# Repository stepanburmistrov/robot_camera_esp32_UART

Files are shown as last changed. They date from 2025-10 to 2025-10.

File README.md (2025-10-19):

# Robot View (ESP32-CAM + Arduino) — веб-джойстик, стрим и управление колёсами

> **Проверено:** сборка и прошивка в Arduino IDE c **ESP32 Arduino core 3.0.7** и стандартным Arduino AVR core (Nano/Uno).  
> **Связь:** UART-пакеты `0xAA 0x55 <L:int8> <R:int8>` на скорости **115200 бод**.

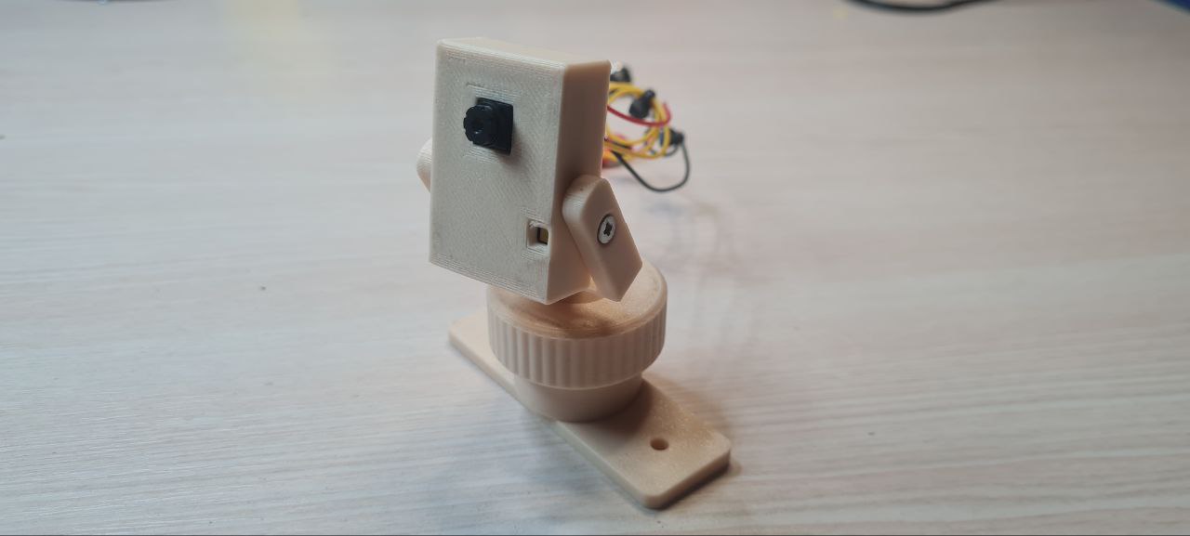
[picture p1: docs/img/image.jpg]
Внешний вид


## Содержание
- [Идея и возможности](#идея-и-возможности)
- [Архитектура](#архитектура)
- [Аппаратная часть и распиновка](#аппаратная-часть-и-распиновка)
- [Установка и сборка](#установка-и-сборка)
- [Веб‑интерфейс](#веб-интерфейс)
- [Команды по UART (CLI ESP32)](#команды-по-uart-cli-esp32)
- [HTTP API](#http-api)
- [Протокол пакетов к Arduino](#протокол-пакетов-к-arduino)
- [Скетчи и логика работы](#скетчи-и-логика-работы)
- [Fail-safe и безопасность](#fail-safe-и-безопасность)

---

## Идея и возможности

**Robot View** объединяет видеострим с ESP32-CAM и управление двухколёсной платформой (танковое руление) через веб-джойстик.  
Под капотом:
- MJPEG-стрим с ESP32-CAM (встроенный веб-сервер).
- Джойстик в браузере (мобильный и десктоп): преобразование `(x,y)` → левое/правое колесо.
- Периодическая передача команд на Arduino по UART (**каждые 30мс**).
- «Стартовый ШИМ» (deadband lift) на стороне ESP32, чтобы колёса уверенно стартовали.
- На Arduino: масштабирование команд ×2 с насыщением, **перестановка L↔R** (см. ниже).
- Аварийный стоп при потере связи; аппаратная кнопка стопа.

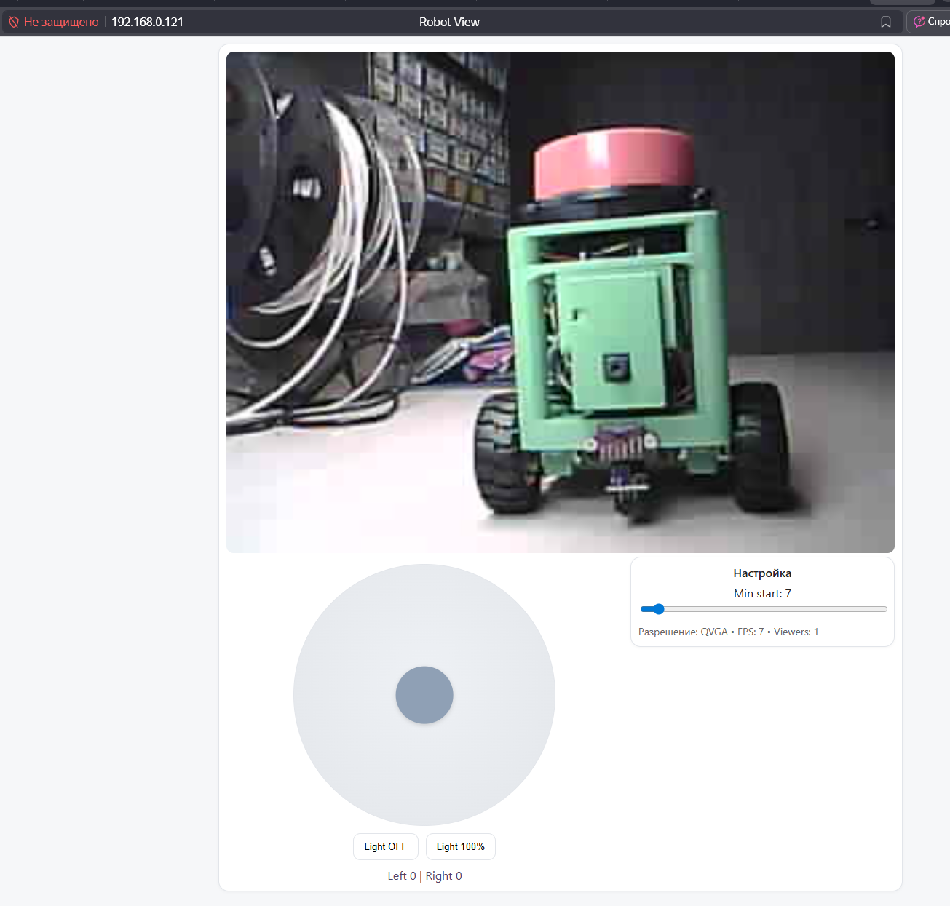
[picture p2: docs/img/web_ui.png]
Веб-интерфейс


---

## Архитектура

ESP32-CAM:
- Поднимает Wi-Fi STA, web UI и MJPEG `/stream`.
- Конвертирует джойстик → `L/R [-127..127]`, сглаживает (EMA), применяет deadband lift.
- Отправляет UART-пакеты `AA 55 L R` на **TX2 = GPIO12** (см. распиновку).

Arduino (Nano/Uno):
- Принимает пакеты, контролирует драйвер Н-мостов.
- Преобразует `int8 [-127..127]` → PWM `[-255..255]` (×2 с насыщением).
- **Важно:** подаёт **R на левое колесо**, а **L на правое** (перевёрнутая кинематика в данном шасси).

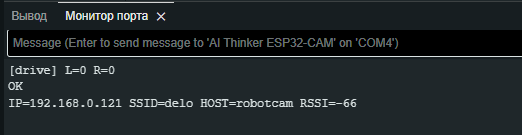
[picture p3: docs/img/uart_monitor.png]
Монитор порта


---

## Аппаратная часть и распиновка

**Связь:** ESP32‑CAM TX2 (GPIO12) → Arduino RX0 (D0). Общая земля GND обязательна.

**Arduino Nano/Uno (скетч `arduino_drive.ino`):**
- `DIR_L = 8`, `PWM_L = 9`
- `DIR_R = 5`, `PWM_R = 6`
- `BUTTON_PIN = 7` *(INPUT_PULLUP — нажато = LOW)* — аварийный STOP
- `LED_HB = 13` — вспышка при приёме пакета

**Скорость порта:** `115200` бод.

**Отладочный приёмник (`arduino_reading.ino`)** — выводит в порт пары `L=.. R=..` для диагностики.

---

## Установка и сборка

> **Проверено:** Arduino IDE + **ESP32 core 3.0.7**. Если у вас иная версия — параметры могут отличаться.
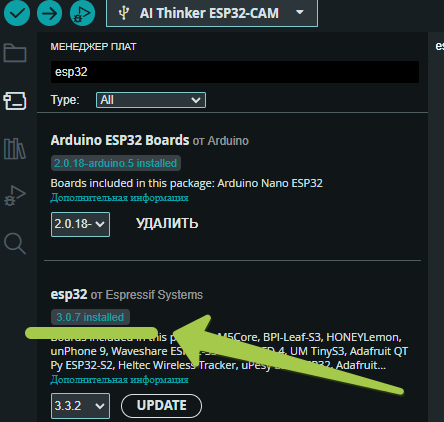
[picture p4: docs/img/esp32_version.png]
Версия ядра


1. **Зависимости/платы:**
   - Установите поддержку плат **ESP32** (верс. 3.0.7) и **Arduino AVR** (Nano/Uno).
2. **ESP32-CAM (скетч `esp32_code.ino`):**
   - Плата: *AI Thinker ESP32‑CAM* (или совместимая).
   - Upload speed 115200–921600; выбор GPIO/PSRAM по вашей плате (скетч настроен под AI Thinker).
3. **Arduino (скетч `arduino_drive.ino`):**
   - Плата: *Arduino Nano (ATmega328P)* или *Uno*.
   - Частота PWM — стандартная (через `analogWrite`). Подключите Н‑мосты к пинам из раздела выше.
4. **Проводка и питание:**
   - ESP32-CAM TX2 (GPIO12) → Arduino D0 (RX0). **GND общий.**
   - Питание двигателей через драйвер моторов с отдельным источником, общим GND.
5. **Первичный запуск:**
   - Прошейте обе платы. Подключитесь к монитору порта ESP32 (115200).

---

## Веб‑интерфейс

Откройте в браузере `http://<ip_esp32>` — появится страница со стримом и круговым джойстиком.  
Особенности:
- Поле‑«полусфера»: при малых |Y| разрешает «поворот на месте» (spin).
- Гамма‑кривая для скорости по Y, мёртвая зона (DEADZONE).
- Кнопки управления вспышкой (LED) и настройка минимального старта (MinStart).

---

## Команды по UART (CLI ESP32)

Через USB-UART (Serial0, монитор порта 115200) доступны команды (по строке, `\n` в конце):

- `SETWIFI|<ssid>|<pass>` — задать Wi-Fi STA (сохранится в NVS).
- `SETHOST|<hostname>` — задать mDNS hostname (и системное имя).
- `SETRES|<QQVGA|QVGA|HVGA|VGA|SVGA|XGA|SXGA|UXGA>` — размер кадра.
- `SETFPS|<1..30>` — частота FPS (кадров/сек).
- `SETJPG|<10..63>` — качество JPEG (меньше число — лучше качество, больше размер).
- `FLASH|<0..100>` — яркость подсветки/вспышки в %.
- `SETMIN|<0..127>` — минимум «подхвата» колёс (см. ниже).
- `IP` — печать IP/host/RSSI.

В ответ — `OK`/`ERR` и/или вывод текущего состояния. Настройки сохраняются в `Preferences (NVS)` и подхватываются при старте.

---

## HTTP API

- `GET /` — веб-страница с UI.
- `GET /stream` — однокадровая JPEG-картинка (для тега `<img>` с автообновлением).
- `GET /drive?l=<int8>&r=<int8>` — немедленная команда (−127..127) с выводом в отладку.
- `GET /flash?val=<0..100>` — задать подсветку.
- `GET /set?min=<0..127>` — задать минимальный старт.
- `GET /info` — JSON со сводкой: `{res,fps,viewers,min}`.

> ESP32 сам обеспечивает **keep-alive**: каждые `30 мс` отправляет текущую команду по UART2, даже если UI молчит.

---

## Протокол пакетов к Arduino

Последовательность байтов:  
`0xAA 0x55 <L:int8> <R:int8>`

- Диапазон `L/R`: −127…127.
- На Arduino (`arduino_drive.ino`) значения **умножаются на 2** с насыщением в `[-255..255]` для PWM.
- **Кинематика шасси:** по месту подключения двигатель/редуктор оказался инвертирован, поэтому
  левому каналу подаётся `R`, правому — `L` (см. код).

Отладочный скетч `arduino_reading.ino` печатает пары `L=.. R=..` только при изменении.  
Для устойчивости парсера используется **таймаут межбайтов** (`30 мс`): при разрыве/мусоре состояние сбрасывается.

---

## Скетчи и логика работы

### `firmware/esp32_code.ino` (ESP32‑CAM)
- Wi‑Fi STA + mDNS, веб‑сервер, стрим.
- Джойстик: deadzone, spin‑порог, гамма‑кривая, EMA‑сглаживание.
- Per‑wheel **deadband lift** (направление‑зависимые пороги `DB_L_F/B`, `DB_R_F/B`).
- UART2 (TX=GPIO12, RX не используется) — отправка пакетов с периодом `30 мс`.
- UART‑CLI команды (см. выше). Настройки в NVS.

### `firmware/arduino_drive.ino` (двигатели)
- Пины: `DIR_L=8, PWM_L=9, DIR_R=5, PWM_R=6`.
- Кнопка STOP на `7` (INPUT_PULLUP). Светодиод «heartbeat» на `13`.
- Парсер `AA 55 L R`, масштабирование ×2, **перестановка L↔R**.
- Журнал каждые `100мс`: `cnt, L, R`.
- Fail‑safe: **STOP**, если нет пакетов дольше `200 мс`.
- Короткая вспышка LED при приёме пакета.

### `firmware/arduino_reading.ino` (диагностика)
- Читает UART, печатает `L/R` при изменениях.

---

## Fail-safe и безопасность

- **Кнопка STOP** на Arduino немедленно обнуляет PWM обоих каналов.
- **Таймаут линка** (по умолчанию 200мс) → автоторможение.
- В UI реализован **жёсткий стоп** при отпускании/уходе вкладки/блокировке экрана.
- Драйверы моторов должны питаться отдельно; **общая земля** обязательна.

---

## STL-модели

Папка `stl/` содержит элементы крепежа/корпуса камеры и шарниров:
- `CamCaseFront.STL`, `CamCaseHolder.STL` — детали корпуса/крепления.
- `Balljoint_bare.STL`, `Balljoint_socket.STL`, `nut.STL` — шарнир и гайка.

---

## Быстрый чек‑лист после прошивки

1. Подключитесь к `Serial` ESP32 (115200) и задайте Wi‑Fi:
   ```
   SETWIFI|MySSID|MyPass
   SETHOST|robot
   IP
   ```
2. Откройте `http://robot.local` или `http://<ip>`.
3. Проверьте движение вперёд/назад, поворот на месте.
4. При необходимости подстройте:
   - `SETMIN|<0..127>` — минимальный старт.
   - `SETFPS|<1..30>`, `SETRES|VGA`, `SETJPG|24` — баланс стрима.
   - В UI: ползунок **MinStart**.

Удачной сборки!

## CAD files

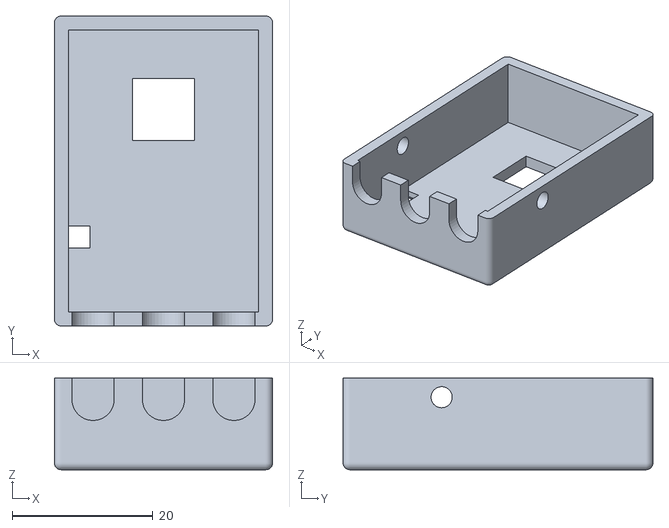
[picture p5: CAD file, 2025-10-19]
stl/CamCaseFront.STL
31.0 x 44.0 x 13.0

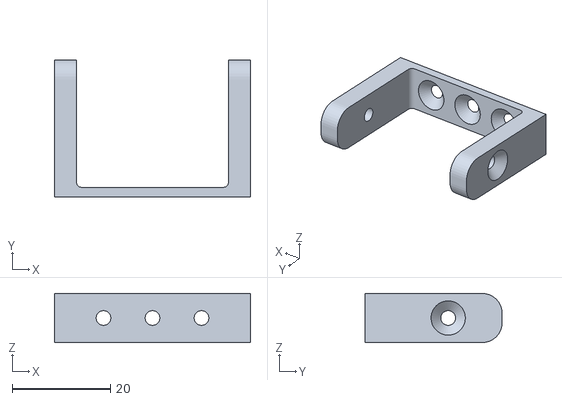
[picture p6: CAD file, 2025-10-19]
stl/CamCaseHolder.STL
40.0 x 28.0 x 10.0

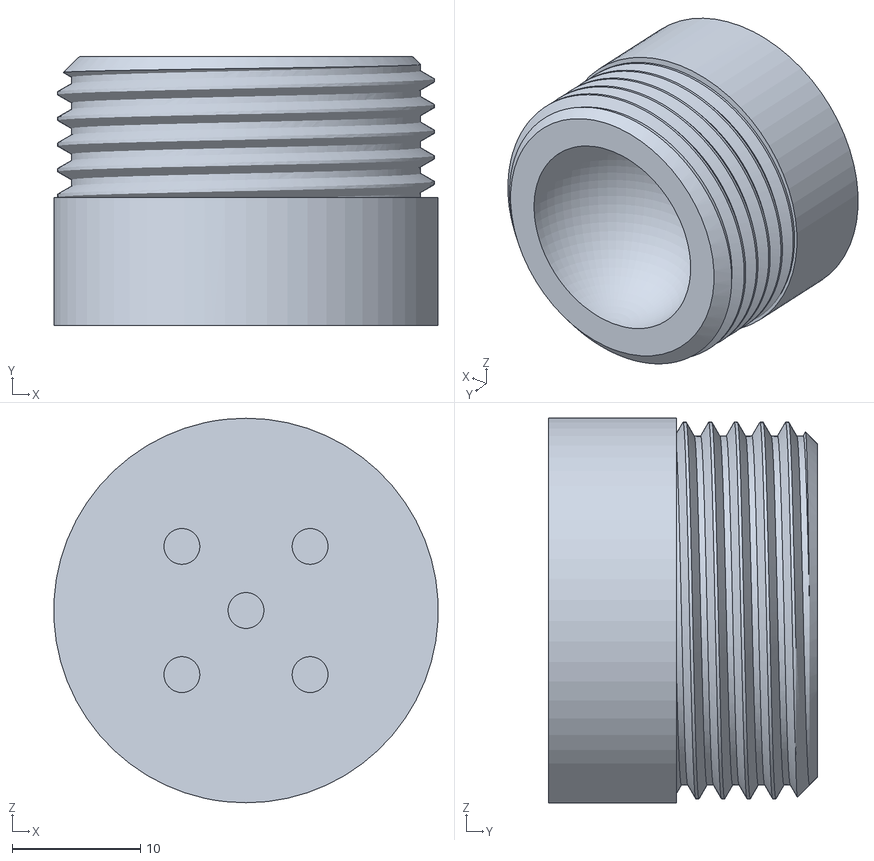
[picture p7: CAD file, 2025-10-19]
stl/Balljoint_socket.STL
30.0 x 21.0 x 30.0

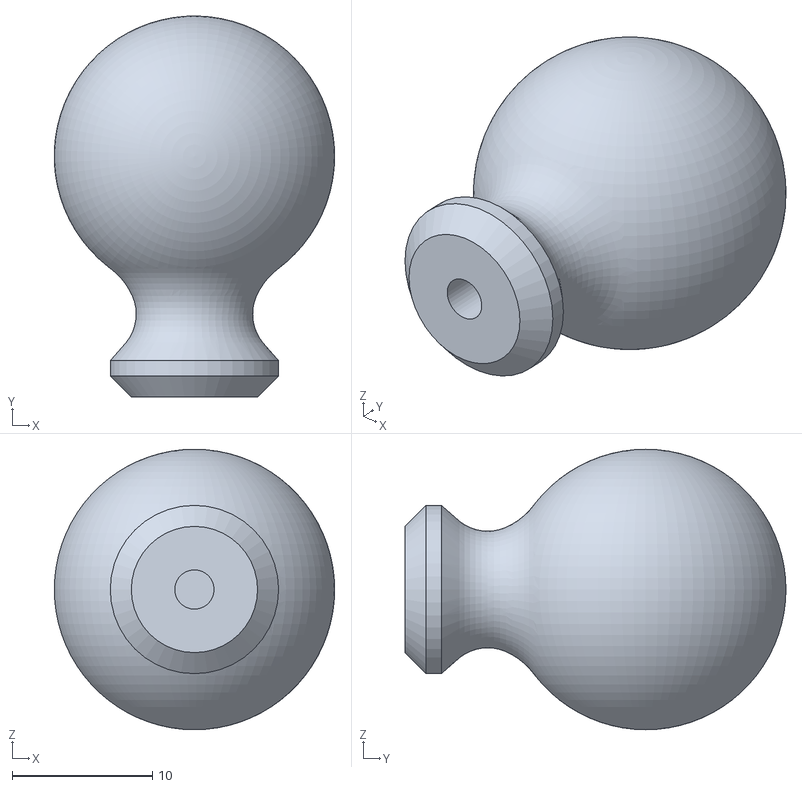
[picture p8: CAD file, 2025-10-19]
stl/Balljoint_bare.STL
20.0 x 27.2 x 20.0

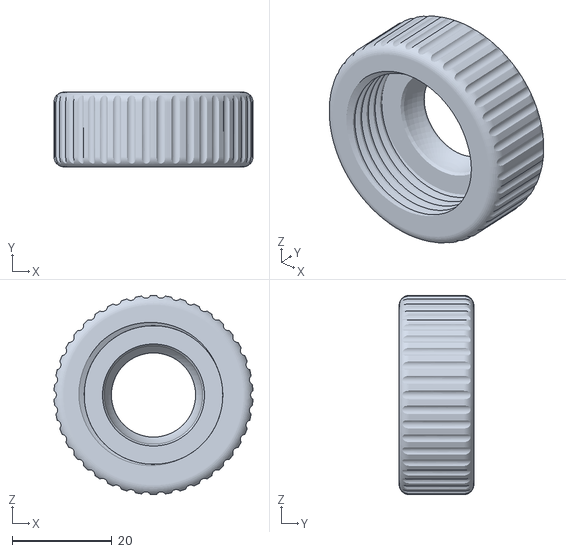
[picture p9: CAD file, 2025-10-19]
stl/nut.STL
40.0 x 15.0 x 40.0

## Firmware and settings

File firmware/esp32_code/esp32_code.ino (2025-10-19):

/*********************************************************************
 * Robot View — ESP32-CAM Web Joystick + MJPEG Stream (v2.4)
 * - UART2: 0xAA 0x55 <int8 L> <int8 R>   (TX2 = GPIO12)
 * - Joystick: symmetric v/w mapping, hemisphere (FWD>=0, REV<=0)
 * - Smoothing: EMA -> per-wheel deadband lift (to overcome start)
 * - Keep-alive: send every 30 ms; debug prints only on change
 * - Safety: hard STOP (L=0,R=0) on release/blur/hidden
 *********************************************************************/

#include "esp_camera.h"
#include <WiFi.h>
#include <Preferences.h>
#include <ESPmDNS.h>

/* ===== UART / Pins ===== */
#define UART0_BAUD   115200
#define UART2_BAUD   115200
#define UART2_RX_PIN -1
#define UART2_TX_PIN 13   // <— TX2 pin to Arduino RX

/* ===== Camera / LED ===== */
#define MAX_CLIENTS  8
#define LED_PIN      4
#define DEF_RES      FRAMESIZE_VGA
#define DEF_FPS      7
#define DEF_JPEGQ    24
#define DEF_FLASH    0

/* ===== Robot control (global) ===== */
#define DEF_MINSTART 80    // визуальный «минимальный старт» в UI (0..127)
#define DEF_HOST     "robot"

/* ===== Keep-alive period (ms) ===== */
#define DRIVE_PERIOD_MS 30

/* ===== Per-wheel deadband lift (0..127 on ESP; *2 на Arduino) =====
 * Пример: на Arduino установлено «стартует с 70 и 100», значит
 * здесь ставим 35 и 50 для FWD/REV соответственно.
 */
#define DB_L_F 35   // левое колесо вперёд
#define DB_L_B 35   // левое назад
#define DB_R_F 50   // правое вперёд
#define DB_R_B 50   // правое назад

/* ===== Steering/easing params ===== */
#define DEADZONE     0.06f   // мёртвая зона по осям
#define SPIN_THR     0.15f   // если |Y| < SPIN_THR — разрешён «spin in place»
#define TURN_GAIN    1.0f    // коэффициент руля (0..1.2 обычно)
#define SPEED_GAMMA  1.2f    // кривая по модулю Y (1.0 = линейно)
#define EMA_ALPHA    0.35f   // сглаживание по L/R (0..1)

/* ===== AI-Thinker pins (OV2640) ===== */
#define PWDN_GPIO_NUM 32
#define RESET_GPIO_NUM -1
#define XCLK_GPIO_NUM 0
#define SIOD_GPIO_NUM 26
#define SIOC_GPIO_NUM 27
#define Y9_GPIO_NUM 35
#define Y8_GPIO_NUM 34
#define Y7_GPIO_NUM 39
#define Y6_GPIO_NUM 36
#define Y5_GPIO_NUM 21
#define Y4_GPIO_NUM 19
#define Y3_GPIO_NUM 18
#define Y2_GPIO_NUM 5
#define VSYNC_GPIO_NUM 25
#define HREF_GPIO_NUM 23
#define PCLK_GPIO_NUM 22

Preferences prefs;
WiFiServer http(80);
HardwareSerial& DRV = Serial2;

WiFiClient streamClients[MAX_CLIENTS];
String ssid, pass, hostname;
framesize_t frameSize;
uint8_t fps, jpgQ, flashPct, minStart;
uint16_t frameIntervalMs;
uint32_t tLastFrame = 0;

uint8_t* lastFrame = nullptr;
size_t lastCap = 0, lastLen = 0;

/* ===== Drive state ===== */
volatile int8_t cmdL = 0, cmdR = 0;   // current command for UART2
int8_t lastDbgL = 127, lastDbgR = 127;
uint32_t tLastDriveSend = 0;

/* ===== Helpers ===== */
static inline int8_t clip127(int v){ if(v<-127) return -127; if(v>127) return 127; return (int8_t)v; }

/* ===== LED PWM ===== */
#define LEDC_LED_MODE  LEDC_LOW_SPEED_MODE
#define LEDC_LED_TIMER LEDC_TIMER_2
#define LEDC_LED_CH    LEDC_CHANNEL_4
#define LEDC_LED_FREQ  5000
#define LEDC_LED_BITS  LEDC_TIMER_12_BIT
static inline void ledcInit(){
  ledc_timer_config_t t={}; t.speed_mode=LEDC_LED_MODE; t.timer_num=LEDC_LED_TIMER;
  t.duty_resolution=LEDC_LED_BITS; t.freq_hz=LEDC_LED_FREQ; t.clk_cfg=LEDC_AUTO_CLK; ledc_timer_config(&t);
  ledc_channel_config_t ch={}; ch.speed_mode=LEDC_LED_MODE; ch.channel=LEDC_LED_CH; ch.gpio_num=LED_PIN;
  ch.timer_sel=LEDC_LED_TIMER; ch.intr_type=LEDC_INTR_DISABLE; ch.duty=0; ch.hpoint=0; ledc_channel_config(&ch);
}
static inline void setLedPct(uint8_t pct){
  flashPct=pct; uint32_t val=(uint32_t)(pct*40.95f);
  ledc_set_duty(LEDC_LED_MODE,LEDC_LED_CH,val); ledc_update_duty(LEDC_LED_MODE,LEDC_LED_CH);
}

/* ===== Camera ===== */
static bool initCamera(){
  camera_config_t c={};
  c.ledc_channel=LEDC_CHANNEL_1; c.ledc_timer=LEDC_TIMER_0;
  c.pin_d0=Y2_GPIO_NUM; c.pin_d1=Y3_GPIO_NUM; c.pin_d2=Y4_GPIO_NUM; c.pin_d3=Y5_GPIO_NUM;
  c.pin_d4=Y6_GPIO_NUM; c.pin_d5=Y7_GPIO_NUM; c.pin_d6=Y8_GPIO_NUM; c.pin_d7=Y9_GPIO_NUM;
  c.pin_xclk=XCLK_GPIO_NUM; c.pin_pclk=PCLK_GPIO_NUM; c.pin_vsync=VSYNC_GPIO_NUM; c.pin_href=HREF_GPIO_NUM;
  c.pin_sscb_sda=SIOD_GPIO_NUM; c.pin_sscb_scl=SIOC_GPIO_NUM; c.pin_pwdn=PWDN_GPIO_NUM; c.pin_reset=RESET_GPIO_NUM;
  c.xclk_freq_hz=8000000; c.pixel_format=PIXFORMAT_JPEG; c.frame_size=frameSize; c.jpeg_quality=jpgQ;
  c.fb_count=psramFound()?2:1; c.grab_mode=CAMERA_GRAB_LATEST; c.fb_location=CAMERA_FB_IN_PSRAM;
  if(esp_camera_init(&c)!=ESP_OK){ Serial.println("STATUS|ERR=CAM"); return false; }
  if(sensor_t* s=esp_camera_sensor_get()) s->set_quality(s, jpgQ);
  return true;
}
static inline framesize_t str2size(const String& s){
  if (s=="QQVGA") return FRAMESIZE_QQVGA; if (s=="QVGA") return FRAMESIZE_QVGA; if (s=="HVGA") return FRAMESIZE_HVGA; if (s=="VGA") return FRAMESIZE_VGA;
  if (s=="SVGA") return FRAMESIZE_SVGA; if (s=="XGA") return FRAMESIZE_XGA; if (s=="SXGA") return FRAMESIZE_SXGA; if (s=="UXGA") return FRAMESIZE_UXGA;
  return (framesize_t)255;
}
static inline const char* size2str(framesize_t fs){
  switch(fs){case FRAMESIZE_QQVGA:return "QQVGA";case FRAMESIZE_QVGA:return "QVGA";case FRAMESIZE_HVGA:return "HVGA";case FRAMESIZE_VGA:return "VGA";
  case FRAMESIZE_SVGA:return "SVGA";case FRAMESIZE_XGA:return "XGA";case FRAMESIZE_SXGA:return "SXGA";case FRAMESIZE_UXGA:return "UXGA";default:return "?";}
}
static inline int activeClients(){int n=0; for(int i=0;i<MAX_CLIENTS;i++) if(streamClients[i]&&streamClients[i].connected()) n++; return n;}

/* ===== UART2 send ===== */
static inline void sendDrivePkt(int8_t L,int8_t R,bool printDbg){
  uint8_t pkt[4]={0xAA,0x55,(uint8_t)L,(uint8_t)R};
  DRV.write(pkt,4);
  if(printDbg && (L!=lastDbgL || R!=lastDbgR)){ lastDbgL=L; lastDbgR=R; Serial.print("[drive] L="); Serial.print(L); Serial.print(" R="); Serial.println(R); }
}

/* ===== HTML (UI + mapping) ===== */
static const char INDEX_HTML[] PROGMEM = R"HTML(
<!doctype html><html lang="ru"><head>
<meta charset="utf-8"><meta name="viewport" content="width=device-width, initial-scale=1, viewport-fit=cover, maximum-scale=1">
<title>Robot View</title>
<style>
  :root{--bg:#f6f7f9;--card:#fff;--txt:#222;--mut:#666;--br:#e2e5ea}
  *{box-sizing:border-box} body{margin:0;background:var(--bg);color:var(--txt);font:16px/1.4 -apple-system,BlinkMacSystemFont,Segoe UI,Roboto,Inter,Arial;user-select:none}
  .wrap{max-width:960px;margin:0 auto;padding:10px}
  .card{background:var(--card);border:1px solid var(--br);border-radius:14px;box-shadow:0 1px 4px rgba(0,0,0,.04);padding:10px}
  #video{width:100%;border-radius:10px}
  .joy-wrap{display:flex;flex-direction:column;align-items:center;gap:10px;margin-top:10px}
  #pad{touch-action:none;width:min(72vw,360px);height:min(72vw,360px);max-width:360px;max-height:360px;border-radius:50%;
       background:radial-gradient(ellipse at 50% 45%, #eef1f5, #e3e6ea); border:1px solid var(--br); position:relative; overflow:hidden}
  #knob{position:absolute;width:22%;height:22%;left:50%;top:50%;transform:translate(-50%,-50%);border-radius:50%;background:#8fa0b5;box-shadow:0 2px 6px rgba(0,0,0,.15)}
  .btns{display:flex;gap:10px;flex-wrap:wrap;justify-content:center}
  button{border:1px solid var(--br);background:#fff;border-radius:10px;padding:10px 14px;cursor:pointer}
  .stats{color:#546;text-align:center}
  .settings{margin-top:8px;color:#666;font-size:14px;text-align:center}
  @media (min-width:900px){ .row{display:flex;gap:10px} .left{flex:1 1 60%}.right{flex:1 1 40%}.settings{text-align:left}}
</style>
</head><body>
<div class="wrap">
  <div class="card">
    <img id="video" src="/stream" alt="stream">
    <div class="row">
      <div class="left joy-wrap">
        <div id="pad"><div id="knob"></div></div>
        <div class="btns">
          <button id="off">Light OFF</button>
          <button id="on">Light 100%</button>
        </div>
        <div class="stats" id="stats">Left 0 | Right 0</div>
      </div>
      <div class="right">
        <div class="card">
          <div style="margin-bottom:6px;font-weight:600;text-align:center">Настройка</div>
          <div style="text-align:center">
            Min start: <span id="minv">-</span>
            <input id="min" type="range" min="0" max="127" step="1" value="80" style="width:100%">
            <div class="settings">
              Разрешение: <span id="res">-</span> • FPS: <span id="fps">-</span> • Viewers: <span id="vw">-</span>
            </div>
          </div>
        </div>
      </div>
    </div>
  </div>
</div>

<script>
const pad=document.getElementById('pad'), knob=document.getElementById('knob'), stats=document.getElementById('stats');
const minR=document.getElementById('min'), minV=document.getElementById('minv');
const resV=document.getElementById('res'), fpsV=document.getElementById('fps'), vwV=document.getElementById('vw');

let minStart=80;
fetch('/info').then(r=>r.json()).then(j=>{minStart=j.min||80;minR.value=minStart;minV.textContent=minStart;resV.textContent=j.res;fpsV.textContent=j.fps;vwV.textContent=j.viewers;});

let rect,cx,cy,R,dragging=false;
function layout(){rect=pad.getBoundingClientRect();cx=rect.left+rect.width/2;cy=rect.top+rect.height/2;R=rect.width*0.45;}
addEventListener('resize',layout,{passive:true}); layout();

const DZ=0.06, SPIN_THR=0.15, SPEED_GAMMA=1.2, TURN_GAIN=1.0, ALPHA=0.35;

let sL=0, sR=0, wantL=0, wantR=0, lastSentL=999, lastSentR=999, aborter=null;

function clamp127(v){return v<-127?-127:(v>127?127:(v|0));}
function scaleSpeed(norm){ if(norm<=0) return 0; const k=Math.pow(norm,SPEED_GAMMA); return Math.round(minStart+(127-minStart)*k); }

// v/w mapping with hemisphere rule
function mapStick(nx,ny){
  let ax=Math.abs(nx), ay=Math.abs(ny);
  nx = (ax<DZ)?0:Math.sign(nx)*(ax-DZ)/(1-DZ);
  ny = (ay<DZ)?0:Math.sign(ny)*(ay-DZ)/(1-DZ);

  if (Math.abs(ny)<SPIN_THR && Math.abs(nx)>DZ){
    const s=scaleSpeed(Math.abs(nx));
    return [ -Math.sign(nx)*s, Math.sign(nx)*s ];
  }

  const v = ny;                 // -1..1
  const w = nx;                 // -1..1
  const s = scaleSpeed(Math.abs(v));  // 0..127

  const t = Math.min(1, Math.abs(w)*TURN_GAIN); // 0..1
  let L = s*(1 - t*Math.sign(v)*Math.sign(w)); // несимметричные? — знак v учитываем
  let R = s*(1 + t*Math.sign(v)*Math.sign(w));

  if (v>=0){ L=Math.max(0,L); R=Math.max(0,R); } else { L=-Math.max(0,L); R=-Math.max(0,R); }
  return [clamp127(Math.round(L)), clamp127(Math.round(R))];
}

// EMA -> show -> queue
function applyAndShow(L,R){
  sL = Math.round(sL + ALPHA*(L - sL));
  sR = Math.round(sR + ALPHA*(R - sR));
  stats.textContent=`Left ${sL} | Right ${sR}`;
  wantL=sL; wantR=sR;
}

function updateFromPointer(x,y){
  let dx=x-cx, dy=cy-y;
  const len=Math.hypot(dx,dy), k=len>R?R/len:1; dx*=k; dy*=k;
  const [L,Rv]=mapStick(dx/R, dy/R);
  knob.style.transform=`translate(calc(-50% + ${dx}px), calc(-50% + ${-dy}px))`;
  applyAndShow(L,Rv);
}

// hard STOP and immediate 0
function hardStop(){
  sL=0;sR=0;wantL=0;wantR=0;lastSentL=999;lastSentR=999;
  stats.textContent='Left 0 | Right 0';
  knob.style.transform='translate(-50%,-50%)';
  fetch('/drive?l=0&r=0',{cache:'no-store'}).catch(()=>{});
}

pad.addEventListener('pointerdown',e=>{dragging=true;pad.setPointerCapture(e.pointerId);layout();updateFromPointer(e.clientX,e.clientY);e.preventDefault();});
pad.addEventListener('pointermove',e=>{if(!dragging)return;updateFromPointer(e.clientX,e.clientY);e.preventDefault();});
function release(e){ if(!dragging)return; dragging=false; hardStop(); e.preventDefault(); }
pad.addEventListener('pointerup',release); pad.addEventListener('pointercancel',release); pad.addEventListener('pointerleave',release);
addEventListener('blur',hardStop); document.addEventListener('visibilitychange',()=>{ if(document.hidden) hardStop(); });

// Send on change only (ESP keeps periodic keep-alive itself)
function loopSend(){
  if (wantL!==lastSentL || wantR!==lastSentR){
    lastSentL=wantL; lastSentR=wantR;
    if(aborter) aborter.abort();
    aborter = new AbortController();
    fetch(`/drive?l=${lastSentL}&r=${lastSentR}`,{signal:aborter.signal,cache:'no-store'}).catch(()=>{});
  }
  requestAnimationFrame(loopSend);
}
requestAnimationFrame(loopSend);

// UI buttons
document.getElementById('off').onclick=()=>fetch('/flash?val=0');
document.getElementById('on').onclick =()=>fetch('/flash?val=100');
minR.oninput=e=>{minStart=+e.target.value;minV.textContent=minStart;};
minR.onchange =()=>fetch('/set?min='+minStart);
</script>
</body></html>
)HTML";

/* ===== HTTP ===== */
static void acceptClients(){
  WiFiClient nc=http.available(); if(!nc) return; nc.setTimeout(50);
  String line=nc.readStringUntil('\n'); line.trim();
  uint32_t t0=millis();
  while (millis()-t0<120){ if(!nc.available()){ delay(1); continue; } String h=nc.readStringUntil('\n'); if(h=="\r"||h.length()==0) break; }

  if (line.startsWith("GET /stream")){
    for(int i=0;i<MAX_CLIENTS;i++){
      if(!streamClients[i]||!streamClients[i].connected()){
        streamClients[i]=nc; streamClients[i].setNoDelay(true);
        streamClients[i].printf("HTTP/1.1 200 OK\r\nContent-Type: multipart/x-mixed-replace; boundary=frame\r\nCache-Control: no-store, no-cache, must-revalidate\r\nPragma: no-cache\r\nConnection: keep-alive\r\n\r\n");
        return;
      }
    }
    nc.printf("HTTP/1.1 503 Service Unavailable\r\nConnection: close\r\n\r\nBusy"); nc.stop(); return;
  }

  if (line.startsWith("GET /jpg")){
    camera_fb_t* fb=esp_camera_fb_get();
    if(!fb){ nc.printf("HTTP/1.1 500\r\nConnection: close\r\n\r\n"); nc.stop(); return; }
    nc.printf("HTTP/1.1 200 OK\r\nContent-Type: image/jpeg\r\nContent-Length: %u\r\nCache-Control: no-store, no-cache\r\nConnection: close\r\n\r\n", fb->len);
    nc.write(fb->buf, fb->len); esp_camera_fb_return(fb); nc.stop(); return;
  }

  if (line.startsWith("GET /drive?")){
    int lpos=line.indexOf("l="), rpos=line.indexOf("r=");
    int amp=line.indexOf('&',lpos), sp=line.indexOf(' ',rpos);
    int l=0,r=0; if(lpos>0&&amp>lpos) l=line.substring(lpos+2,amp).toInt(); if(rpos>0&&sp>rpos) r=line.substring(rpos+2,sp).toInt();

    // перехватываем команду от UI (уже после EMA), дальше на UART2 уходит периодически
    cmdL=clip127(l); cmdR=clip127(r);
    sendDrivePkt(cmdL,cmdR,true); // немедленно + отладка при изменении

    nc.printf("HTTP/1.1 204 No Content\r\nConnection: close\r\n\r\n"); nc.stop(); return;
  }

  if (line.startsWith("GET /flash?")){
    int p=line.indexOf("val="), sp=line.indexOf(' ',p); int v=(p>0&&sp>p)?line.substring(p+4,sp).toInt():flashPct;
    if(v<0)v=0; if(v>100)v=100; setLedPct(v); prefs.putUChar("flash",flashPct);
    nc.printf("HTTP/1.1 200 OK\r\nConnection: close\r\n\r\nOK"); nc.stop(); return;
  }

  if (line.startsWith("GET /set?")){
    int p=line.indexOf("min="), sp=line.indexOf(' ',p);
    if(p>0&&sp>p){ int m=line.substring(p+4,sp).toInt(); if(m<0)m=0; if(m>127)m=127; minStart=m; prefs.putUChar("min",minStart); }
    nc.printf("HTTP/1.1 200 OK\r\nConnection: close\r\n\r\nOK"); nc.stop(); return;
  }

  if (line.startsWith("GET /info")){
    nc.printf("HTTP/1.1 200 OK\r\nContent-Type: application/json\r\nCache-Control: no-store\r\nConnection: close\r\n\r\n");
    nc.printf("{\"min\":%u,\"res\":\"%s\",\"fps\":%u,\"viewers\":%d}", (unsigned)minStart, size2str(frameSize), (unsigned)fps, activeClients());
    nc.stop(); return;
  }

  nc.printf("HTTP/1.1 200 OK\r\nContent-Type: text/html; charset=utf-8\r\nCache-Control: no-store\r\nConnection: close\r\n\r\n");
  nc.write_P(INDEX_HTML, strlen_P(INDEX_HTML)); nc.stop();
}

/* ===== Streaming ===== */
static void broadcastFrame(const uint8_t* buf,size_t len){
  for(int i=0;i<MAX_CLIENTS;i++){
    auto &c=streamClients[i]; if(!c||!c.connected()){ c.stop(); continue; }
    if(c.printf("--frame\r\nContent-Type: image/jpeg\r\nContent-Length: %u\r\n\r\n",(unsigned)len)<=0){ c.stop(); continue; }
    size_t sent=0; uint32_t t0=millis();
    while(sent<len){
      if(!c.connected()){ c.stop(); break; }
      int chunk=(int)min((size_t)1024, len-sent);
      int w=c.write(buf+sent, chunk);
      if(w<=0){ if(millis()-t0>60){ c.stop(); break; } delay(1); continue; }
      sent+=w;
    }
    if(!c||!c.connected()) continue;
    if(c.write("\r\n",2)!=2){ c.stop(); continue; }
  }
}

/* ===== UART CLI ===== */
static void handleUart(){
  static String buf;
  while(Serial.available()){
    char c=Serial.read(); if(c=='\r') continue; if(c!='\n'){ buf+=c; continue; }
    buf.trim();
    if(buf.startsWith("SETWIFI|")){ int p=buf.indexOf('|',8); if(p>8){ ssid=buf.substring(8,p); pass=buf.substring(p+1); prefs.putString("ssid",ssid); prefs.putString("pass",pass); WiFi.begin(ssid.c_str(), pass.c_str()); Serial.println("OK"); } else Serial.println("ERR"); }
    else if(buf.startsWith("SETHOST|")){ hostname=buf.substring(8); hostname.trim(); if(!hostname.length()) hostname=DEF_HOST; prefs.putString("host",hostname); WiFi.setHostname(hostname.c_str()); Serial.println("OK"); }
    else if(buf.startsWith("SETRES|")){ framesize_t ns=str2size(buf.substring(7)); if(ns!=255){ frameSize=ns; prefs.putUChar("res",ns); esp_camera_deinit(); initCamera(); Serial.println("OK"); } else Serial.println("ERR"); }
    else if(buf.startsWith("SETFPS|")){ int nf=buf.substring(7).toInt(); if(nf>=1&&nf<=30){ fps=nf; frameIntervalMs=1000/fps; prefs.putUChar("fps",fps); Serial.println("OK"); } else Serial.println("ERR"); }
    else if(buf.startsWith("SETJPG|")){ int q=buf.substring(7).toInt(); if(q>=10&&q<=63){ jpgQ=q; prefs.putUChar("jpgq",jpgQ); if(sensor_t*s=esp_camera_sensor_get()) s->set_quality(s, jpgQ); Serial.println("OK"); } else Serial.println("ERR"); }
    else if(buf.startsWith("FLASH|")){ int v=buf.substring(6).toInt(); if(v<0)v=0; if(v>100)v=100; setLedPct(v); prefs.putUChar("flash",flashPct); Serial.println("OK"); }
    else if(buf.startsWith("SETMIN|")){ int m=buf.substring(7).toInt(); if(m<0)m=0; if(m>127)m=127; minStart=m; prefs.putUChar("min",minStart); Serial.println("OK"); }
    else if(buf=="IP"){ Serial.print("IP="); Serial.print(WiFi.localIP()); Serial.print(" SSID="); Serial.print(WiFi.SSID()); Serial.print(" HOST="); Serial.print(WiFi.getHostname()); Serial.print(" RSSI="); Serial.println(WiFi.RSSI()); }
    else Serial.println("ERR");
    buf="";
  }
}

/* ===== Setup / Loop ===== */
void setup(){
  Serial.begin(UART0_BAUD);
  DRV.begin(UART2_BAUD, SERIAL_8N1, UART2_RX_PIN, UART2_TX_PIN);
  ledcInit(); prefs.begin("cfg", false);

  ssid=prefs.getString("ssid",""); pass=prefs.getString("pass",""); hostname=prefs.getString("host",DEF_HOST);
  frameSize=(framesize_t)prefs.getUChar("res",DEF_RES);
  fps=prefs.getUChar("fps",DEF_FPS); if(fps<1||fps>30) fps=DEF_FPS;
  jpgQ=prefs.getUChar("jpgq",DEF_JPEGQ); if(jpgQ<10||jpgQ>63) jpgQ=DEF_JPEGQ;
  frameIntervalMs=1000/fps; setLedPct(prefs.getUChar("flash",DEF_FLASH));
  minStart=prefs.getUChar("min",DEF_MINSTART);

  WiFi.mode(WIFI_STA); WiFi.setSleep(false); WiFi.setHostname(hostname.c_str());
  if(ssid.length()) WiFi.begin(ssid.c_str(), pass.c_str());
  if(MDNS.begin(hostname.c_str())) MDNS.addService("http","tcp",80);

  initCamera(); http.begin();
  tLastDriveSend = millis();
}

void loop(){
  handleUart();
  acceptClients();

  // periodic keep-alive
  if (millis() - tLastDriveSend >= DRIVE_PERIOD_MS){
    tLastDriveSend = millis();
    // Пер-колёсный «подхват» (lift) в UART-пакете — чтобы ардуина видела сразу достаточную команду
    int L = cmdL, R = cmdR;

    auto lift = [](int v, int dbF, int dbB)->int{
      if (v==0) return 0;
      int s = abs(v);
      int db = (v>0) ? dbF : dbB;   // разные пороги на вперёд/назад
      // поднимаем к db, сохраняя масштаб 0..127
      int out = db + ( (127 - db) * s ) / 127;
      if (out>127) out=127;
      return (v>0)? out : -out;
    };

    L = lift(L, DB_L_F, DB_L_B);
    R = lift(R, DB_R_F, DB_R_B);

    sendDrivePkt(clip127(L), clip127(R), false);
  }

  if (millis() - tLastFrame < frameIntervalMs) return;
  tLastFrame = millis();

  camera_fb_t* fb = esp_camera_fb_get(); if(!fb) return;
  if (fb->len > lastCap){ free(lastFrame); lastFrame=(uint8_t*)ps_malloc(fb->len); lastCap=lastFrame? fb->len : 0; }
  if (lastFrame && lastCap>=fb->len){ memcpy(lastFrame, fb->buf, fb->len); lastLen = fb->len; } else lastLen = 0;
  esp_camera_fb_return(fb);
  if (lastLen) broadcastFrame(lastFrame, lastLen);
}

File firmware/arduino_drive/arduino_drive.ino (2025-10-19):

// === Робот: приём от ESP32-CAM (0xAA 0x55 L R), *2, НО L/R ПЕРЕСТАВЛЕНЫ МЕСТАМИ ===
// Пины моторов:
#define DIR_L  8
#define PWM_L  9
#define DIR_R  5
#define PWM_R  6

// Кнопка экстренной остановки
#define BUTTON_PIN 7   // INPUT_PULLUP (нажато = LOW)

// Светодиод "сердцебиение" при приёме пакета
#define LED_HB 13

// Последовательный порт от камеры:
#define RX_BAUD 115200

// Протокол от ESP32-CAM:
const uint8_t H1 = 0xAA;
const uint8_t H2 = 0x55;

// Тайминги/защита
const uint16_t BYTE_TIMEOUT_MS  = 30;    // межбайтовый таймаут парсера
const uint16_t LINK_TIMEOUT_MS  = 1000;  // если нет пакетов дольше — STOP
const uint16_t PRINT_EVERY_MS   = 100;   // периодический лог состояния

// Текущее состояние
int speedL = 0;   // -255..255 (то, что реально подали на ЛЕВОЕ колесо)
int speedR = 0;   // -255..255 (то, что реально подали на ПРАВОЕ колесо)
volatile uint32_t packetCount = 0;

// --- Управление каналом DIR/PWM (ваша логика) ---
void wheelChannel(uint8_t DIR, uint8_t PWM, int speed) {
  speed = constrain(speed, -255, 255);
  if (speed > 0) {
    digitalWrite(DIR, LOW);
    analogWrite(PWM, speed);              // 0..255
  } else if (speed < 0) {
    digitalWrite(DIR, HIGH);
    analogWrite(PWM, 255 - abs(speed));   // инвертированный ШИМ
  } else {
    digitalWrite(DIR, LOW);
    analogWrite(PWM, 0);
  }
}
inline void leftWheel(int s)  { wheelChannel(DIR_L, PWM_L, s); }
inline void rightWheel(int s) { wheelChannel(DIR_R, PWM_R, s); }

void STOP() {
  wheelChannel(DIR_L, PWM_L, 0);
  wheelChannel(DIR_R, PWM_R, 0);
}

// --- Парсер пакетов 0xAA 0x55 L R на RX0 ---
enum { ST_H1, ST_H2, ST_L, ST_R } state = ST_H1;
uint32_t tLastByte = 0;
uint32_t tLastPacket = 0;

int8_t inL = 0, inR = 0;

void feedByte(uint8_t b) {
  switch (state) {
    case ST_H1:
      state = (b == H1) ? ST_H2 : ST_H1;
      break;
    case ST_H2:
      if (b == H2) state = ST_L;
      else state = (b == H1) ? ST_H2 : ST_H1;
      break;
    case ST_L:
      inL = (int8_t)b;
      state = ST_R;
      break;
    case ST_R:
      inR = (int8_t)b;
      state = ST_H1;
      tLastPacket = millis();
      packetCount++;

      digitalWrite(LED_HB, HIGH);  // короткий всплеск при приёме

      // масштабирование: *2 с насыщением
      long Lraw = (long)inL * 2;
      long Rraw = (long)inR * 2;
      int Lscaled = (int)constrain(Lraw, -255, 255);
      int Rscaled = (int)constrain(Rraw, -255, 255);

      // ВАЖНО: МЕНЯЕМ МЕСТАМИ — левому колесу даём R, правому — L
      speedL = Rscaled;
      speedR = Lscaled;

      leftWheel(speedL);
      rightWheel(speedR);
      break;
  }
}

void readSerialPackets() {
  if (millis() - tLastByte > BYTE_TIMEOUT_MS && state != ST_H1) {
    state = ST_H1;
  }
  while (Serial.available() > 0) {
    tLastByte = millis();
    uint8_t b = (uint8_t)Serial.read();
    feedByte(b);
  }
}

// --- Кнопка экстренной остановки (антидребезг) ---
byte lastRaw = HIGH, stable = HIGH;
uint32_t lastBounceAt = 0;
const uint16_t debounceMs = 30;

void handleButton() {
  byte raw = digitalRead(BUTTON_PIN);
  if (raw != lastRaw) { lastBounceAt = millis(); lastRaw = raw; }
  if (millis() - lastBounceAt > debounceMs) {
    if (stable != raw) {
      stable = raw;
      if (stable == LOW) {
        STOP(); speedL = speedR = 0;
        Serial.println(F("STOP (button)"));
      }
    }
  }
}

void setup() {
  pinMode(DIR_L, OUTPUT); pinMode(PWM_L, OUTPUT);
  pinMode(DIR_R, OUTPUT); pinMode(PWM_R, OUTPUT);
  pinMode(BUTTON_PIN, INPUT_PULLUP);
  pinMode(LED_HB, OUTPUT);
  digitalWrite(LED_HB, LOW);

  STOP();

  Serial.begin(RX_BAUD); // RX0: сюда приходит поток от ESP32 (и отсюда печать в монитор)
  Serial.println(F("Robot RX ready @115200 (AA 55 L R, *2, L<->R swapped)"));
  Serial.println(F("Wiring: ESP32 TX->D0(RX), GND common"));

  tLastPacket = millis();
}

void loop() {
  readSerialPackets();
  handleButton();

  // погасить всплеск на LED через ~1 мс
  static uint32_t tLedOff = 0;
  if (digitalRead(LED_HB) == HIGH) {
    if (tLedOff == 0) tLedOff = millis();
    if (millis() - tLedOff >= 1) { digitalWrite(LED_HB, LOW); tLedOff = 0; }
  }

  // периодический лог (даже если значения не менялись)
  static uint32_t tLastPrint = 0;
  if (millis() - tLastPrint >= PRINT_EVERY_MS) {
    tLastPrint = millis();
    Serial.print(F("cnt=")); Serial.print(packetCount);
    Serial.print(F("  L=")); Serial.print(speedL);
    Serial.print(F("  R=")); Serial.println(speedR);
  }

  // Fail-safe: если давно нет пакетов — стоп
  if (millis() - tLastPacket > LINK_TIMEOUT_MS) {
    if (speedL != 0 || speedR != 0) {
      STOP(); speedL = speedR = 0;
      Serial.println(F("STOP (link timeout)"));
    }
  }
}
